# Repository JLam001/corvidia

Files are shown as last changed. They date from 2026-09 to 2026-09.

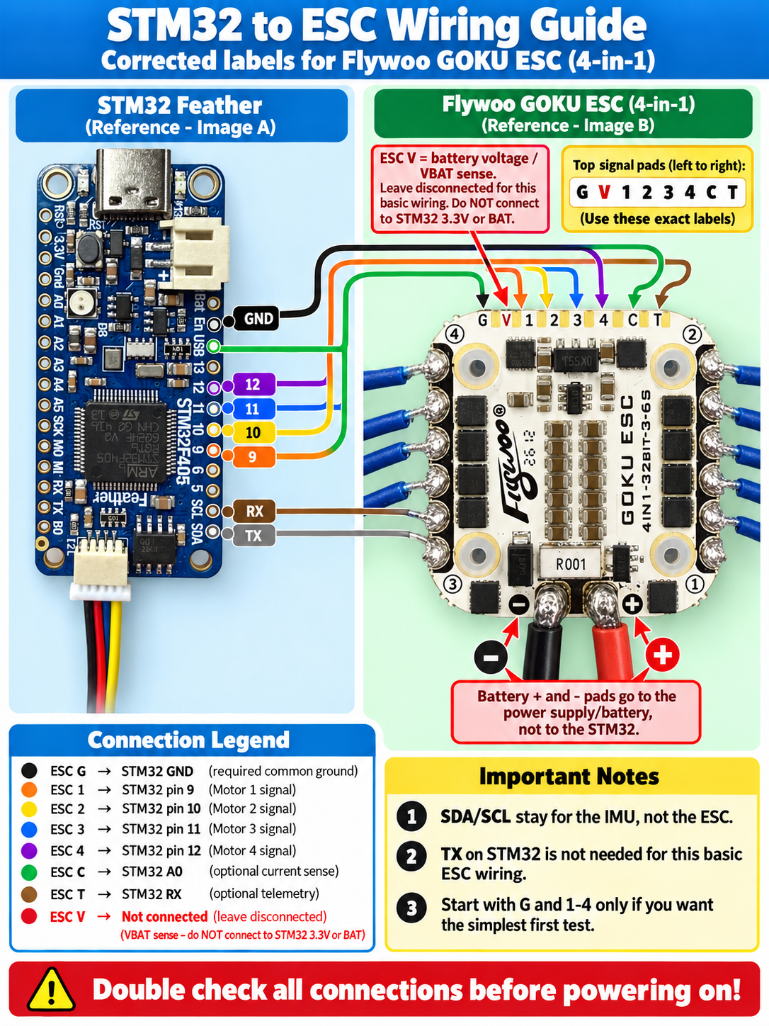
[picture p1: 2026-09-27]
docs/references/control/user-wiring-3.png

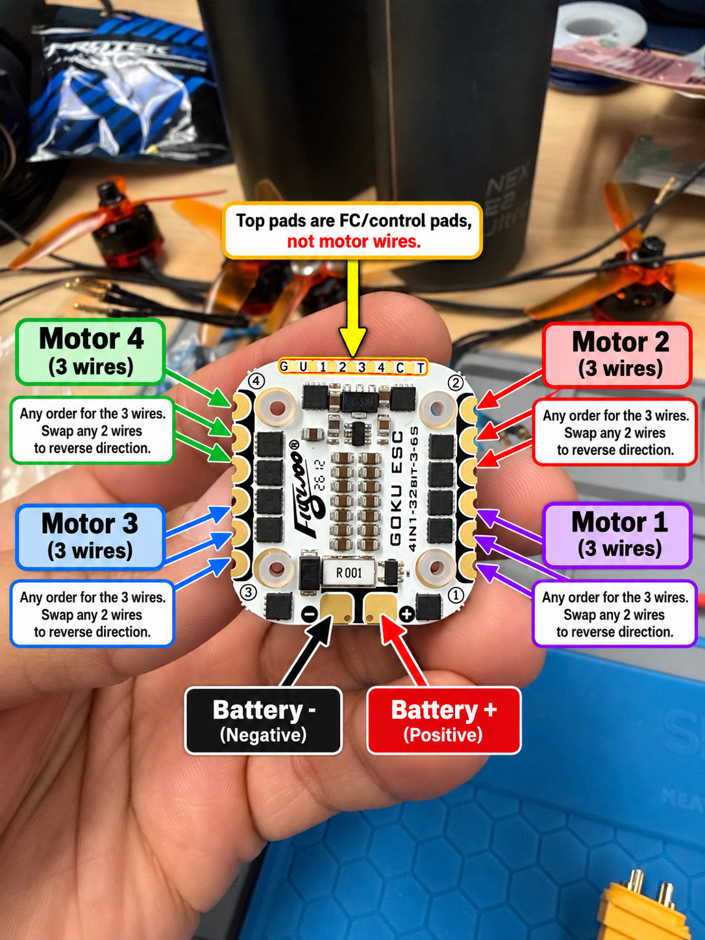
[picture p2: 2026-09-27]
docs/references/control/user-wiring-1.png

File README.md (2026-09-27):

# Corvidia

Project repository for the Corvidia bench demonstrator.

## Mechanical frame

The final frame, editable CAD, manufacturing references and print setup live in
[`hardware/frame/`](hardware/frame/README.md).

- [Prepared P2S PLA print project](hardware/frame/output/Compact_P2S_PLA/Corvidia_Compact_P2S_PLA_Motor_Holes_Fixed.3mf)
- [Print and assembly guide](hardware/frame/output/Compact_P2S_PLA/START_HERE.md)
- [Complete frame package](hardware/frame/output/Corvidia_Compact_One_Print.zip)

The frame has a flat center for a 95 × 111 mm tray, four reinforced motor arms,
and a braced camera mount. It prints on one 256 × 256 mm plate. Physical hardware
fit and operating checks are documented in the guide.

## Software

- [Onboard mission console](perception/STAND_DEMO.md): search briefs, timed
  collection, saved images, and the tested 5% motor-input demo profile.
- [Perception pipeline](perception/README.md): person detection, tracking, and video replay.
- [Event pipeline design](docs/event-pipeline.md): confirmation and evidence workflow.
- [STM32 firmware import](firmware/IMPORT.md): BNO085 IMU polling, MAVLink telemetry,
  command handling, and host-test results.
- [Motor controls and corrected wiring](firmware/MOTOR_CONTROL.md): individual ESC
  tests, the planned motor layout, and bounded movement proposals.
- [Firmware guide](firmware/README.md): PlatformIO setup, installed v5 bench
  firmware, and the prepared v6 startup ramp.

## Repository layout

```text
docs/             # Software architecture and design
perception/       # Jetson person detection/event pipeline
firmware/         # Feather STM32F405 PlatformIO project
hardware/
  frame/
    cad/          # Parametric CAD, build/check scripts and printer profiles
    references/   # Manufacturer geometry and drawings
    output/       # Final print files, CAD exports and verification records
```

Mechanical files live under `hardware/`; Jetson software and STM32 firmware
are separate projects under `perception/` and `firmware/`.

## Get the complete files

Large CAD and print files use Git LFS. Install Git LFS, then run:

```sh
git lfs install
git clone https://github.com/JLam001/corvidia.git
cd corvidia
git lfs pull
```

For an existing checkout, run `git lfs pull` before opening CAD or print files.
See the [frame README](hardware/frame/README.md) for editing and rebuilding.

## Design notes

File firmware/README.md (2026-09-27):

# Corvidia STM32F405 firmware

**Current installed firmware: v5.** It supports selectable operator envelopes through 100% input and
60,000 ms, defaulting to 5% / 500 ms. See [DSHOT_V5.md](DSHOT_V5.md) and the
[installation status](../docs/references/control/dshot-v5-install-2026-09-27.md).
V5 all-four tests at 5% and 7.5% for one second, 50% for 200 ms and two
seconds, and 20% for ten seconds passed user-observed spin/stop checks. This is bench firmware; mission/LLM flight outputs remain unavailable.

**V6 startup ramp is deferred.** Its opt-in source profile is retained in
[DSHOT_V6.md](DSHOT_V6.md), but it has not been installed or verified with
powered motors. The active Jetson adapter requires v5; the prepared v6 host
changes are archived outside this checkout. V5 applies requested input
immediately. The default PlatformIO build remains the IMU-only `feather_f405`
profile, so v5 and v6 motor-capable images both require explicit selection.

PlatformIO + STM32duino firmware for the Adafruit Feather STM32F405 and BNO085.
See [IMPORT.md](IMPORT.md) for provenance and [MOTOR_CONTROL.md](MOTOR_CONTROL.md)
for motor wiring, bench interlocks, and the future movement interface.

**DShot individual and all-four bench pulses passed observed spin/stop checks**
at 1% input for 200 ms, followed by all four at 5% for 500 ms. See the [test record](../docs/references/control/dshot-powered-tests-2026-09-27.md).
Legacy PWM remains blocked after its earlier motor-4 incident. Disconnect the ESC
battery between bench sessions.

## Firmware builds

| Environment | Behavior |
| --- | --- |
| `feather_f405` (default) | IMU + MAVLink over USB; no motor outputs |
| `feather_f405_bench` | Motor-test protocol with hardware outputs disabled |
| `feather_f405_bench_pwm` | Explicit PWM bench image; no IMU or flight stabilization |
| `feather_f405_pwm_diagnostic` | Measures output-pad pulse timing; ESC battery must be disconnected |
| `feather_f405_dshot_diagnostic` | DShot diagnostic with signal pads held low |
| `feather_f405_dshot_signal` | DShot300 zero-throttle frames only; ESC battery must be disconnected |
| `feather_f405_dshot_imu` | IMU + bounded command protocol; ESC signals disabled |
| `feather_f405_dshot_imu_signal` | IMU + zero DShot frames; nonzero commands disabled |
| `feather_f405_dshot_imu_bench` | IMU + explicitly enabled individual or all-four tests; short bench pulses verified |
| `feather_f405_dshot_imu_ramp` | Deferred v6 candidate with a fixed five-second startup ramp; not installed or powered-verified |
| `native` | Hardware-independent C++ tests |
| `native_ramp` | Hardware-independent ramp tests compiled with the v6 identity/capability |

See [DSHOT.md](DSHOT.md) for the new STM32 driver, its MAVLink diagnostics and
validation limits. The combined individual/all-four DShot bench image is now v5, flashed and
verified byte-for-byte; see the installation record for live verification status. It includes the IMU sequence freshness
fix. Live attitude/quaternion telemetry runs at about 50 Hz; both test modes
are reported available, all startup inputs are zero, and stop is acknowledged. Switching test modes needs no reflash.
Both modes require explicit commands and default to a 5% input / 500 ms envelope.
V5 supports explicit envelopes up to 100% / 60 seconds; input is not measured RPM. DShot execution requires per-test readiness; simultaneous
execution also requires individual physical stop checks. Flight control is unavailable.

The [mission control candidate](MISSION_CONTROL.md) adds selectable mission
duration, a configurable ceiling up to 100%, a separate nominal collective,
bounded LLM movement intents and session expiry. It is tested offline and is not
connected to ESC outputs or dispatched by the installed firmware.

The default source sends HEARTBEAT, ATTITUDE, ATTITUDE_TARGET and STATUSTEXT.
ATTITUDE_TARGET is a command echo, not a measured attitude. The default source
now gates ATTITUDE on separate attitude/gyro freshness checks. The shared IMU
wrapper uses game rotation vector (relative yaw), validates reports and clears
health on reset. Message arrival alone does not prove sensor capture latency.

The board observed on September 27 also sent ATTITUDE_QUATERNION, SYS_STATUS,
SERVO_OUTPUT_RAW, SYSTEM_TIME and EXTENDED_SYS_STATE. That running image has not
yet been matched to source. It was backed up and restored byte for byte after
the PWM bench investigation; its 50 Hz attitude stream was verified again.
It has since been backed up again before installing the zero-throttle DShot
diagnostic. Do not assume the original image implements the local bench protocol.

```sh
cd firmware
pio run -e feather_f405
pio test -e native
```

## Live MAVLink IMU dashboard

From the repository root:

```sh
python3 -m venv .venv-control
.venv-control/bin/python -m pip install -r firmware/tools/requirements-control.txt
.venv-control/bin/python firmware/tools/imu_viz.py
```

Open **http://127.0.0.1:8765**. The dashboard provides:

- 3D orientation, roll/pitch/yaw in degrees, gyro rates in degrees/second.
- A 15-second gyro plot, message rate, packet age, heartbeat and board messages.
- Reported gyro/accelerometer health and reported output pulses when available.
- A stale indication after 500 ms without valid ATTITUDE; automatic USB reconnect.
- DShot mode, IMU freshness, command limits enabled/disabled, faults and requested
  motor inputs when the integrated firmware is installed. Motor RPM is unavailable.

It only listens. It sends no MAVLink packets, heartbeats, arming or motor commands.
The HTTP server binds to localhost. No external web assets are needed.
Only one application should own the serial port: close any serial monitor first,
and stop this dashboard with Ctrl+C before running the motor tool.

Auto-detection only selects STM32 USB VID/PID `0483:5740`. It refuses to guess
between multiple boards. Override with `--port /dev/cu.usbmodem...`; source IDs
default to `1/1` and can be set using `--system` and `--component`.

### Interpreting the display

MAVLink ATTITUDE uses radians and rad/s; the dashboard converts both to degrees.
Axes follow the reported sensor frame. Verify physical sensor mounting and the
sensor-to-airframe transform before using this orientation for stabilization.
A roll near ±180° means the reported frame is inverted relative to zero roll;
the visualizer deliberately does not hide that with an automatic zero offset.

SYS_STATUS health flags and SERVO_OUTPUT_RAW values are firmware reports.
They do not independently measure I2C freshness, ESC acceptance, or motor RPM.
An unknown value is shown as unavailable. Disconnection dims the last orientation.

Protocol reference: [MAVLink common messages](https://mavlink.io/en/messages/common.html#ATTITUDE).

## Uploading

See the full [bench instructions](MOTOR_CONTROL.md) before changing images.
The Feather F405 enters ROM DFU with **BOOT0 tied to 3.3 V, then RESET**.
Remove the BOOT0 jumper before resetting into the application. Disconnect ESC
telemetry from RX during DFU; the ROM bootloader also listens on serial interfaces.
Keep motor power disconnected during flashing.

Manufacturer: [Feather F405 DFU details](https://learn.adafruit.com/adafruit-stm32f405-feather-express/dfu-bootloader-details).

## Host checks

```sh
.venv-control/bin/python -m unittest discover -s firmware/tools -p 'test_*.py' -v
```

These cover MAVLink wire decoding, unit conversion, stale/disconnected display
state, source filtering, rejected invalid samples, reconnect state, and motor
command bounds. They do not replace hardware verification.

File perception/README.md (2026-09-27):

# Perception: person detection event pipeline

For the integrated camera, person-description mission, live IMU, and bounded
motor interface, see the [stand demo guide](STAND_DEMO.md). Its default
observation mode uses real perception with simulated motor commands.
Ordinary briefs stop after the first saved match. A brief such as
**find as many people as possible within 30 seconds** collects matching images
for the requested duration (1–60 seconds). The console shows the capture count
and latest image; the full collection is stored on the Jetson. See
[timed collection missions](STAND_DEMO.md#timed-collection-missions) for behavior
and counting limits.

Implements [`docs/event-pipeline.md`](../docs/event-pipeline.md):

- **Step 1, event core:** typed records, candidate lifecycle, bounded queues, stub
  confirmer, evidence writer, deterministic detection-event tests.
- **Step 2, video replay:** YOLO11n + explicitly configured ByteTrack, every-frame
  and real-time replay, live CSI camera source, MJPEG preview, run reports.
- **Step 3, local Cosmos:** Cosmos Reason 2 2B (Q4_K_M) on llama.cpp behind the
  confirmer interface, a labeled starter crop set, and an evaluation tool.
- **Step 4, Jetson CSI:** GStreamer capture with Argus buffer timestamps,
  selectable sensor mode (default 1080p from the binned 1080p60 mode), power
  mode in reports, a 10 s timeseries for drift, and a detached soak runner.
- **Depth and best shot:** per-event metric distance from Depth Anything V2 Metric
  Small (TensorRT, uncalibrated until checked with a tape measure) and the
  clearest full-resolution view of each tracked person (`best.jpg`).
- **Step 5 tooling:** clip recorder and a YOLO-alone vs YOLO + Cosmos scorer.
- The live detector runs the YOLO11n TensorRT engine directly (no PyTorch or
  Ultralytics at runtime) with a NumPy ByteTrack.

## Layout

```text
src/corvidia_perception/
  records.py        # frames, detections, candidates, results, skips
  config.py         # settings from the spec (TOML-loadable), not yet calibrated
  crop.py           # 20% padded crop, size/blur gates, frozen copies
  gate.py           # persistence gate, lifecycle, suppression, retry cooldown
  confirm_queue.py  # bounded FIFO, one entry per track, 2 s expiry
  confirmer.py      # backend protocol, strict answer parsing, stub backends
  worker.py         # evidence commit, one active request, deadline, drain/recover
  evidence.py       # atomic writes, storage limits, interrupted-event recovery
  pipeline.py       # EventPipeline wiring + LatestFrameSlot
  health.py         # counters, gauges, faults
  simulate.py       # threaded run on synthetic detections
  detector.py       # detector factory + tracker wrapper with dropped-frame aging
  trt_detector.py   # YOLO on TensorRT: letterbox, zero-copy managed buffers, NMS
  bytetrack.py      # ByteTrack (NumPy), matches Ultralytics' tracker output
  cosmos.py         # llama-server adapter: JSON-schema answers, cancel + idle check
  cosmos_eval.py    # corvidia-cosmos-eval: accuracy/latency on labeled crops
  trt_runtime.py    # shared TensorRT runner (mapped pinned buffers via ctypes)
  depth.py          # Depth Anything V2 metric distance per event
  depth_check.py    # corvidia-depth-check: live distance readout for calibration
  best_shot.py      # clearest crop per track -> best.jpg / best.json
  record.py         # corvidia-record: camera clips for evaluation
  encounter_eval.py # corvidia-encounter-eval: YOLO vs YOLO + Cosmos on clips
  sources.py        # video replay (every/realtime) and Argus CSI camera
  preview.py        # annotated MJPEG preview + /health JSON
deploy/
  cosmos_server.sh  # pinned llama.cpp container for Cosmos
  export_yolo.sh    # build the YOLO11n TensorRT engine
  soak.sh           # detached sustained-load run (start/status/stop)
  run.py            # corvidia-run CLI and run report
```

The detector thread calls `EventPipeline.on_frame(frame, detections)`. The
confirmation worker runs on its own thread (`start()`), or is stepped with
`tick()` in tests using a fake clock.

## Jetson setup (once)

The venv must see the system OpenCV (GStreamer/Argus build) and TensorRT, so it
is created with system site-packages. `pyproject.toml` blocks the pip OpenCV
wheels and pins NumPy < 2 to match the system OpenCV.

```sh
cd ~/corvidia/perception
uv venv --python /usr/bin/python3 --system-site-packages
uv sync --extra detector
mkdir -p ~/models && curl -sL -o ~/models/yolo11n.pt \
  https://github.com/ultralytics/assets/releases/download/v8.3.0/yolo11n.pt
```

The live pipeline uses the FP16 TensorRT engine (`~/models/yolo11n.engine`) and
never imports PyTorch. The `detector` extra (Ultralytics + PyTorch) is only for
exporting the engine, `.pt` comparisons, and parity tests. Build the engine once
(about 10 minutes):

```sh
deploy/export_yolo.sh
```

PyTorch in the tooling extra comes from the `cu130` index, which has no native
sm_87 (Orin) build; `test_gpu_detections_match_cpu` checks its GPU results.

## Cosmos confirmer

```sh
deploy/cosmos_server.sh start    # fetch pinned weights (sha256-checked), run container
deploy/cosmos_server.sh status
```

llama-server runs in the Jetson AI Lab container (pinned by digest) on
`127.0.0.1:8010`, restarting with the system. It uses the community GGUF
`Kbenkhaled/Cosmos-Reason2-2B-GGUF` (Q4_K_M + F16 vision projector) pinned to a
revision, with `-c 2048 -np 1 -cram 0` to keep RAM headroom.

## Run on the Jetson

From the repository root on the Mac:

```sh
rsync -az --delete --exclude='.git' --exclude='.DS_Store' --exclude='.venv' \
  --exclude='__pycache__' --exclude='.pytest_cache' ./ jlam@192.168.2.2:corvidia/
ssh jlam@192.168.2.2 'cd ~/corvidia/perception && ~/.local/bin/uv run pytest -q'
```

On the Jetson (`cd ~/corvidia/perception`):

```sh
# Accuracy replay: every frame, event timing on video time, instant stub answers
uv run corvidia-run --video /usr/share/opencv4/samples/data/vtest.avi --mode every

# Timing replay: real-time pacing (here 4x) with frame dropping
uv run corvidia-run --video /usr/share/opencv4/samples/data/vtest.avi --mode realtime --speed 4

# Live CSI camera with Cosmos, depth and preview at http://192.168.2.2:8080/  (Ctrl-C to stop)
uv run corvidia-run --camera --confirmer cosmos --preview-port 8080

# Confirmer accuracy/latency on the labeled crop set, and failure-path checks
uv run corvidia-cosmos-eval --dataset ~/corvidia-data/eval/starter --checks
```

Useful flags: `--model ~/models/yolo11n.pt` (PyTorch path), `--confirmer cosmos|yes|no|uncertain`,
`--stub-delay 0.8`, `--duration 60`, `--config settings.toml`.
Events default to `~/corvidia-data/events/<session>/`, outside the rsync target,
and each session gets a `run_report.json` (detector/loop/frame-age percentiles,
drops, events, skips, peak RSS, peak system memory, max temperatures).

## Step 3 measurements (Orin Nano 8 GB, 2026-09-27)

Starter crop set (`~/corvidia-data/eval/starter`, 255 crops hand-labeled from
vtest.avi, a live session, background regions, and Megamind.avi animation):

| Model, prompt | Person recall | Confirm precision | Background rejected | Cartoons rejected | Latency p50 / p99 |
|---|---|---|---|---|---|
| Q8_0, default prompt | 121/121 | 0.87 | 30/34 | 1/15 | 1.53 / 2.75 s |
| **Q4_K_M, default prompt (deployed)** | 120/121 | 0.95 | 34/34 | 9/15 | 1.35 / 2.46 s |
| Q4_K_M, "physically present" prompt | 41/121 | 1.00 | 34/34 | 15/15 | 1.26 / 2.40 s |

The model never answered "uncertain". Rewording the prompt swings results
sharply, so prompt changes need a larger held-out set with real screens, photos
and mannequins before they are adopted.

Full stack, 4 min real-time replay with Cosmos Q4 (TensorRT detector, no PyTorch):
0 dropped frames at 10 fps; detector p50 22.5 ms idle vs 36.5 ms while Cosmos
runs (GPU contention); confirmation p50 1.51 s, p99 1.77 s, no timeouts; minimum
available RAM 1.73 GB (desktop session running); max 53.8 °C.

Failure paths against the real server: mid-generation cancel acknowledged with
the server idle after ~1.0 s; a 4K image maps to `context_overflow`; a stopped
server maps to `server_unavailable`.

Memory (camera run, 20 s): TensorRT-only pipeline costs 655 MB and runs the
detector at 22.9 ms p50; the Ultralytics/PyTorch path cost 1,051 MB at 52.7 ms.

## Step 4: camera and sustained load (2026-09-27)

Capture is a GStreamer pipeline read through PyGObject (the venv sees the
system `gi`). Each frame's `capture_ts` is the Argus buffer timestamp on
CLOCK_MONOTONIC (`capture_quality: "argus_buffer_pts"`): the time Argus
delivered the frame, about 4.5 ms before Python receives it. It is not the
exposure time; Argus does not expose sensor timestamps through GStreamer, and
that would need a small C++ Argus capture.

Capture cost by mode (capture only, 15 W):

| Sensor mode -> output | CPU (1 core) | Argus-to-Python | Frame |
|---|---|---|---|
| 1080p60 mode -> 720p @ 30 | 33% | 6 ms | 2.8 MB |
| **1080p60 mode -> 1080p @ 30 (default)** | 44% | 10 ms | 6.2 MB |
| 4K30 mode -> 1080p @ 30 | 43% | 13 ms | 6.2 MB |
| 4K30 mode -> 4K @ 30 | 118% | 38 ms | 24.9 MB |

YOLO letterboxes every frame to 640 px, so resolution mainly sharpens the crops
Cosmos sees. The binned 1080p mode reads out faster (less rolling-shutter skew)
and is less noisy in low light than the 4K mode.

```sh
deploy/soak.sh start 30   # camera + YOLO + Cosmos, detached, preview on :8080
deploy/soak.sh status     # latest timeseries row
deploy/soak.sh stop       # graceful stop; writes run_report.json
```

## Free-space stream (depth thread)

The pipeline order for a moving platform: the depth engine runs on its own thread at a fixed
rate and publishes an obstacle free-space profile, the detector thread tracks people and the
gate stores evidence with per-event distance, and no confirmer sits in the loop. The default
confirmer is the `yes` stub; live runs delay it by `--stub-delay` (0.8 s, to emulate Cosmos
latency), so pass `--stub-delay 0` for the no-confirmer order. Cosmos stays available with
`--confirmer cosmos`.

```sh
uv run corvidia-run --camera --freespace-hz 10 --stub-delay 0 --preview-port 8080
uv run corvidia-run --camera --freespace-hz 10 --stub-delay 0 --freespace-udp 127.0.0.1:5601   # also as JSON datagrams
```

`FreeSpaceStream` (`depth_stream.py`) always works on the newest frame (a one-frame fan-out
from the run loop), turns each metric depth map into seven sector "nearest" distances and free
scores (`freespace.py`, ported from the autodrone framework with the same field names: `t`,
`columns`, `center_free`, `all_close`, `hfov_deg`, `nearest_m`), smooths the nearest distances
with an EMA, and stamps each profile at publish time. Per session it appends
`freespace.jsonl` (one row per publish with the map's `age_at_publish_ms` and `depth_ms`),
sets `freespace_*` health gauges (also in `timeseries.jsonl` and `/health`), and adds a
`freespace` block to `run_report.json`. Parameters live in `[freespace]` of the config
(`n_cols`, `near_percentile`, `band`, `hfov_deg`, `d_stop`, `d_free`, `smooth_alpha`, `udp`).

Budget on the Orin Nano (measured per-call costs, 15 W): depth ~46 ms idle and YOLO ~22.5 ms,
so depth at 10 Hz plus YOLO at 10-15 fps fits with headroom; while a Cosmos confirmation runs,
depth takes 100-140 ms and YOLO 36.5 ms, and a consumer with a 150 ms freshness rule (the
autodrone L3/L4 layers) would see stale free space. The engine is shared with the per-event
distance through a lock in `DepthEstimator.depth_map`; the two take turns. Not yet done:
calibration (`depth.scale`), the outdoor 80 m engine, an attitude-driven band (the fixed
0.35-0.8 band is used until pitch is available), and a rate measurement on the Jetson itself.
Per-frame person tracks can leave the process the same way: `--tracks-udp host:port` sends
`{"t", "frame_id", "source_epoch", "width", "height", "tracks": [{"id", "x1", "y1", "x2", "y2",
"conf", "age", "depth_m"}]}` after every processed frame (`tracks_stream.py`; boxes normalized,
`age` = processed frames seen, `depth_m` = torso median from the newest free-space map or -1).
[`bridge/`](bridge/README.md) turns both streams and the evidence store into the autodrone
mission loop's topics. The laptop evaluation harness and its datasets are in
[`laptop-eval/`](laptop-eval/README.md).

## Depth and best shot

```sh
# once: export and build the engines (conversion venv has torch + transformers)
python tools/export_depth.py ~/models/depth/da2-metric-indoor-small-hf \
    ~/models/depth/da2-metric-indoor-small-294x518.onnx
/usr/src/tensorrt/bin/trtexec --onnx=...onnx --saveEngine=...engine --fp16
# calibrate: stand at taped distances and compare
uv run corvidia-depth-check
```

Depth runs once per event, on the event's frame, on the confirmation worker
thread while Cosmos runs (about 46 ms idle, 100-140 ms under load; 24 ms of GPU
time). Distance is the median over the central torso region of the box. Values
stay `"uncalibrated"` until `[depth] scale` and `calibrated = true` are set.

TensorRT buffers are pinned host memory mapped into the GPU (zero-copy). CUDA
managed memory cannot be used: the Orin reports `concurrentManagedAccess = 0`, so
CPU access during any kernel faults, and YOLO and depth run on different threads.

## Soak and step 5 results (2026-09-27)

30 min soak at 15 W, 1080p, Cosmos Q4: 106 events (98 confirmed, 7 rejected, 1
timeout), confirmation p50 2.06 s / p99 3.00 s, max 54.6 °C. Available RAM fell
from 1.3 GB to 0.92 GB while the camera ran and recovered after it stopped; the
growth is outside the pipeline process and not yet diagnosed.

Step 5 on three recorded clips (people walking, a group, an empty ceiling view):
YOLO alone had 0 false events, so Cosmos removed none; both found 4/4 people.
Track fragmentation produced 32 events for 4 people. Hard negatives (screens,
posters) were not captured, so Cosmos's benefit is still unmeasured.

## Not yet covered

- Merging duplicate events from fragmented tracks (about 8 events per person on
  close-range clips).
- Depth calibration against a tape measure; distances are uncalibrated.
- Argus sensor timestamps: live frames carry host arrival time only.
- Dataset-collection retention quotas and automatic retention policies.
- Hard negatives (screens, printed photos, mannequins, statues) in the eval set,
  and a held-out split for prompt changes.
- Calibrated `person_score` (the spec keeps it null for now).
- YOLO11n and Ultralytics are AGPL-3.0; a commercial product needs a licence or
  a differently licensed detector.

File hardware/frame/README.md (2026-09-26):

# Corvidia — final compact frame

## Print file

[Corvidia_Compact_P2S_PLA_Motor_Holes_Fixed.3mf](output/Compact_P2S_PLA/Corvidia_Compact_P2S_PLA_Motor_Holes_Fixed.3mf)

Open as a project in Bambu Studio. Configured for **Bambu P2S, 0.4 mm standard nozzle, Generic PLA and Textured PEI**. Keep the saved placement at 100% scale; do not auto-arrange.

- One connected part on one 256 × 256 mm plate.
- Approximately 6h 4m and 185 g PLA, including supports and brim.
- Flat 110 × 116 mm center for the user's 95 × 111 mm tray.
- Arms taper from 28 mm roots to 20 mm ends; 6 mm deck and motor pads.
- Four motor mounts and a braced, forward-facing camera bracket.
- Verified open motor screw and center relief holes in the sliced paths.

See the [print and assembly guide](output/Compact_P2S_PLA/START_HERE.md) for hardware, placement and physical checks.

## Files kept

| Location | Contents |
|---|---|
| `output/Compact_P2S_PLA/` | Final print project, FreeCAD, STEP, STL, guide, previews and current verification records |
| `output/Corvidia_Compact_One_Print.zip` | Final package, including CAD sources, profiles and component references |
| `cad/` | Final build, slicing and verification scripts; shared geometry definitions and parameters |
| `cad/profiles/` | P2S machine, Generic PLA and final process settings |
| `references/` | Component source geometry/drawings needed to understand and rebuild the design |

## Edit and rebuild

Run `cad/Open_Compact.FCMacro` in FreeCAD to open the editable model with its Python definitions loaded. The model uses named spreadsheet parameters and procedural solids.

From this workspace on this Mac:

```sh
PYTHONPATH=/Applications/FreeCAD.app/Contents/Resources/lib /Applications/FreeCAD.app/Contents/Resources/bin/python cad/compact_frame.py
python3 cad/slice_compact.py
python3 cad/check_compact.py
```

The slicer script defaults to `/Applications/BambuStudio.app`; use `--app` to specify another installation. Python verification requires Pillow. `cad/prepare_references.py` regenerates the Orin cache from the retained manufacturer STEP if needed.

Rebuilding replaces generated outputs and creates temporary files under `tmp/`. The saved print project and CAD have passed software checks; physical tray fit, adhesive, motor screw engagement, assembled balance, temperatures, strength and bench restraint still require hardware checks.

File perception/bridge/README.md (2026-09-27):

# Corvidia -> autodrone bridge

`corvidia_bridge.py` is the process that lets the autodrone mission loop run on top of this
pipeline. `corvidia-run` owns the camera and the GPU models and publishes two UDP streams; the
bridge turns them, plus the evidence store, into the bus topics the framework's nodes consume.

| Bus topic | Source in Corvidia | Notes |
|---|---|---|
| `perc.freespace` | `corvidia-run --freespace-hz 10 --freespace-udp 127.0.0.1:5601` | FreeSpace fields forwarded unchanged, stamped at Corvidia's publish time |
| `perc.tracks` | `corvidia-run --tracks-udp 127.0.0.1:5602` | PersonTracks fields unchanged: normalized boxes, id, conf, age (processed frames seen), depth_m (torso median from the newest depth map) |
| `health.perception` | liveness of the tracks stream | stale after `stale_s` (1 s); free-space staleness only appears in the detail, because the mission guard judges free-space age itself |
| `health.camera` | frame ids advancing in the tracks stream; Corvidia `/health` faults `camera`, `source`, `memory_low` when `health_url` is set | |
| `capture.event` | each completed `event.json` in the newest session under `events_root` | paths: frame.jpg, crop.jpg, best.jpg (waits up to `best_grace_s` for the best shot); `verified` = yes / no / unknown from Cosmos, `unverified` with a stub; events completed before the bridge started are not replayed |
| `cam.frame` (optional) | Corvidia's MJPEG preview (`--preview-port 8080`, `preview_url = "http://127.0.0.1:8080/stream"`) | JPEG frames at `frame_hz`; they carry the drawn boxes, so they serve the CAPTURE burst and the context frame, not clean evidence |

## Running it on the Jetson

```sh
# Corvidia side (its own venv)
cd ~/corvidia/perception
uv run corvidia-run --camera --freespace-hz 10 --stub-delay 0 \
    --freespace-udp 127.0.0.1:5601 --tracks-udp 127.0.0.1:5602 --preview-port 8080

# autodrone side (its environment: pyzmq + the autodrone package)
cd ~/autodrone
python -m autodrone.launch --profile configs/host-jetson.toml --only broker,fc,control,mission
python ~/corvidia/perception/bridge/corvidia_bridge.py --profile configs/host-jetson.toml
```

Do not start the framework's `camera` or `perception` nodes: both would open the same Argus
sensor and run a second detector. The profile may carry a `[corvidia_bridge]` section (every key
optional; defaults shown in the module docstring): ports, `stale_s`, `events_root`, `session`,
`publish_capture`, `best_grace_s`, `health_url`, `preview_url` (the `/stream` endpoint), `frame_hz`. Set `depth_kind = "metric"` in the
profile's perception section if anything on the framework side still assumes the relative model;
the free-space thresholds (`d_stop` 3 m, `d_free` 6 m) are applied on the Corvidia side.

What the mission then sees, in pilot-assisted mode (autodrone `states.py` / `guards.py`):
entering SCOUT needs healthy FC, PERCEPTION and CAMERA; SCOUT and CENTER hold while PERCEPTION
stays healthy and `perc.freespace` stays fresh (older than `depth_stale_s` for `depth_stale_grace_s`
means STOP); `all_close` is not a state change but a controller backoff; a track with `age >= 3`
moves SCOUT to CENTER; CAPTURE needs CAMERA and reads `cam.frame` for its burst (or logs "no camera
frames" and falls to COOLDOWN after 3 s if `preview_url` is unset) while `capture.event` carries
Corvidia's own evidence. With `send_commands = false` nothing reaches the board.

## Tests

`test_bridge.py` covers everything that does not need the bus: UDP receive, datagram
conversion, liveness and heartbeat rules, event tailing across sessions, JPEG dimension parsing
and MJPEG splitting. It runs with the package suite (`uv run pytest -q`; `bridge` is in
`testpaths`). The node itself imports autodrone only when started.

The laptop harness can drive the whole chain without the Jetson:
`laptop-eval/tools/mimic_pipeline.py ... --freespace-udp 127.0.0.1:5601 --tracks-udp 127.0.0.1:5602`,
then the framework's broker and this bridge from the autodrone environment.

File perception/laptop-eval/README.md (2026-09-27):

# Laptop evaluation harness

Runs the perception pipeline on a laptop against public datasets, without the Jetson, and
documents the datasets and results behind the `perception-pipeline` branch. On the Jetson the
same pipeline order is one command (see the main README, "Free-space stream"):

```sh
uv run corvidia-run --camera --freespace-hz 10 --stub-delay 0   # depth thread + YOLO + gate + evidence, no Cosmos
```

What is real here and what is substituted:

| Stage | Jetson | Laptop |
|---|---|---|
| Source | Argus CSI camera or recorded clip | ingested clip directory (same format as `corvidia-record`) |
| Free-space stream | `FreeSpaceStream` + Depth Anything V2 Metric Small on TensorRT | same `FreeSpaceStream`, same model via transformers on CPU |
| Detector | YOLO11n FP16 TensorRT engine | same YOLO11n weights, Ultralytics on CPU |
| Tracker, gate, queue, worker, evidence, best shot | unchanged | unchanged |
| Confirmer | Cosmos (optional) | stub `--confirmer yes` (also the Jetson default) |

## Setup

```sh
cd perception/laptop-eval
./setup.sh              # .venv with CPU torch, ultralytics, opencv, transformers; yolo11n.pt; depth checkpoint
./fetch_datasets.sh     # DanceTrack (3 smallest clips) and MOT17-05, ingested into clips/
```

## Datasets

Used for the results below (fetched by `fetch_datasets.sh`):

| Dataset | Hugging Face id | What it tests | License | Size fetched |
|---|---|---|---|---|
| DanceTrack | `Voxel51/DanceTrack` | 25 fps 1080p mp4, per-frame boxes with identities, head-height, indoor and outdoor groups | CC BY 4.0 | 3 clips, ~23 MB + 83 MB annotations |
| MOT17-05 | `Lekim89/MOT17` (mirror of MOTChallenge) | 14 fps 640x480, moving street-level camera, 88 annotated people, ignore regions and distractor classes | upstream CC BY-NC-SA 3.0 (research use only) | one sequence, ~30 MB |

Other options verified in the 2026-09-27 dataset sweep (not fetched by default):

| Dataset | Hugging Face id | Fit | License |
|---|---|---|---|
| VisDrone2019-MOT | `huseyincavus/visdrone2019-mot` | real UAV footage, oblique from tens of metres, people small; 1.64 GB val split | CC BY-NC 4.0 |
| P-DESTRE | `2uanDM/p-destre` | DJI at 5.5-6.7 m, 45-90 degree pitch, closest to a quadcopter view; 30 fps 4K mp4 with identities; selective download from a 72 GB tar | uploader tag Apache-2.0, upstream research use |
| UAV123 (person sequences) | `xche32/UAV123` | drone following one person at 5-25 m, 30 fps; single 14 GB tarball | not stated |
| Print attack sample | `AxonData/print-attack-dataset` | 15 clips of a camera on a printed photo of a person: hard negative for the confirmer, runs through the whole pipeline | CC BY 4.0 |
| Replay attack sample | `AxonData/Replay_attack_mobile` | 39 clips of a phone filming a screen showing a person: hard negative | CC BY 4.0 |
| PA-100K | `tuandunghcmut/PA-100K` | 100k real surveillance person crops for confirmer positives | CC BY 4.0 |
| COCO 2017 person val | `naufalso/coco-2017-person-val` | still images, detector-only precision/recall | COCO terms |

Any MOTChallenge-style sequence (`img1/`, `seqinfo.ini`, `gt/gt.txt`), FiftyOne video export, or
plain video with a MOT `gt.txt` ingests with `tools/ingest.py`. Clip names must not contain a dot.

## Ingest, run, score

```sh
V=.venv/bin/python
$V tools/ingest.py mot data/mot17/train/MOT17-05-FRCNN --out clips/mot17-05
$V tools/ingest.py fiftyone data/dancetrack/data/dancetrack0008.mp4 \
    --frames data/dancetrack/frames.json --samples data/dancetrack/samples.json --out clips/dancetrack0008
$V tools/ingest.py video some_clip.mp4 --out clips/print-attack-01       # spoof clip, no gt

./run_clip.sh dancetrack0008              # YOLO-alone arm: accuracy replay -> autolabel -> score
./run_clip.sh print-attack-01 --depiction # every track is a depiction, no people
```

Clips are `000000.jpg...` plus `frames.jsonl` with `capture_ts = index / fps` from the dataset's
true frame rate (so the gate's 1 s window is right at 14 fps), `gt.txt` in MOT format, and
`clip.json` with provenance. Frames are re-encoded once at quality 95 at native resolution;
`--max-side` exists only to emulate a camera output size (YOLO letterboxes to 640, depth resizes
to 518x294, and confirmer crops are capped at 448 px regardless).

`tools/autolabel.py` turns `gt.txt` into the `corvidia-encounter-eval` label file: each track's
first event box is matched at its frame by IoU (0.5 person, 0.2 partial, overlap with a MOT
distractor or reflection row = depiction, else not_person). Tracks it will not guess at are left
unlabeled and listed by the scorer: overlaps with ignore regions (conf 0), unmatched boxes at the
frame edge (on MOT17-05 every one was a real person entering or leaving that the annotators did
not box), and frames with no gt. Review those with `corvidia-encounter-eval sheets` and label by
hand; hand labels are never overwritten. A clip's "people" are gt identities with 15+ frames at
visibility >= 0.5, height >= 48 px and width >= 24 px (the crop gate's minimums).

## The pipeline order with the free-space stream

```sh
$V tools/mimic_pipeline.py clips/mot17-05 --events runs/mot17-05 --mode realtime --depth-hz 10
# emulate compute 4x faster than the laptop: replay 4x slower and scale every time constant 4x
$V tools/mimic_pipeline.py clips/mot17-05 --events runs/mot17-05 --mode realtime \
    --speed 0.25 --depth-hz 2.5 --stale-s 0.6 --control-hz 5 --grace-s 2.0
```

Add `--freespace-udp 127.0.0.1:5601 --tracks-udp 127.0.0.1:5602` to feed the bridge in
[`../bridge/`](../bridge/README.md) from the laptop (verified 2026-09-27 with the framework's
broker: 110 track messages, 27 free-space profiles, 11 capture events and healthy heartbeats
reached the bus during a DanceTrack replay).

This drives the packaged `FreeSpaceStream` with the CPU depth model and replays a virtual 20 Hz
controller against `freespace.jsonl`: the fraction of ticks that saw free space younger than the
consumer's rule (150 ms, from the autodrone framework's L3/L4 guards) under both stamping choices,
and how often the L4 guard (stale for 0.5 s) would have fired.

## Results, 2026-09-27

YOLO-alone arm, accuracy replay (every frame, laptop CPU):

| Clip | People | Tracks | False | Precision | Found | Duplicate events | Unlabeled |
|---|---|---|---|---|---|---|---|
| DanceTrack 0008 | 8 | 26 | 0 | 1.00 | 8/8 | 18 | 0 |
| MOT17-05 | 52 | 132 | 3 | 0.975 | 46/52 | 30 | 11 |

Free-space stream + detector, real time (laptop CPU; both PyTorch models contend for the same
cores) and 4x dilated (video-time equivalents, gate/queue windows scaled):

| Run | YOLO fps | Depth Hz (target 10) | Depth inference | Fresh ticks, stamp at publish / capture | Guard stops | Events | Found | Precision |
|---|---|---|---|---|---|---|---|---|
| DanceTrack, real time 1x | 5.5 | 1.2 | 596 ms | 18 % / 0 % | 14 / 1 | 6 | 5/8 | 1.00 |
| MOT17-05, real time 1x | 4.5 | 1.9 | 480 ms | 28 % / 0 % | 3 / 1 | 2 | 2/52 | 1.00 |
| DanceTrack, 4x dilated | 17.0 | 4.6 | 157 ms | 68 % / 0 % | 0 / 1 | 20 | 8/8 | 1.00 |
| MOT17-05, 4x dilated | 14.0 (0 dropped) | 5.0 | 139 ms | 72 % / 0 % | 0 / 2 | 129 | 46/52 | 0.983 |

Reading: at 1x the laptop cannot run both models at rate, the detector starves the gate and the
guard would stop the mission repeatedly. With 4x more compute the detector keeps up, events and
recall return to accuracy-mode levels, and the structure meets the guard only when free space is
stamped at publish time; stamping at capture counts the map's own age (~210-240 ms here, ~56 ms
with the Jetson engine) and fails every tick. Depth reaches half its target because this CPU's
inference is 140-160 ms video-time against the engine's 46 ms. Duplicate events are cross-track
fragmentation (one person, several track ids), the dominant open issue. Depth is uncalibrated
(`scale` 1.0); MOT17-05 is 4:3, so its depth input was stretched by a third.

The JSON reports behind both tables are in `results/2026-09-27/`.

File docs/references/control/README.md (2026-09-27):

# User-provided control references

Copied from Downloads on September 27, 2026:

- `HANDOFF-2026-09-27.md`: original `HANDOFF.md`, describing the perception project.
  It describes commits and uncommitted Jetson work beyond this checkout. This is
  a reference snapshot, not proof that those files or measurements exist locally.
- `user-wiring-1.png`: `ChatGPT Image Sep 27, 2026, 01_17_20 AM.png`.
- `user-wiring-2.png`: `ChatGPT Image Sep 27, 2026, 01_17_36 AM.png`.
- `user-wiring-3.png`: `ChatGPT Image Sep 27, 2026, 01_17_44 AM.png`.

The images are annotated/generated references, not an electrical inspection.
Their arrows and pin labels conflict in places. In particular, Feather D11/D12
do not support hardware PWM. Use the verified manufacturer pin assignments and
the correction table in [MOTOR_CONTROL.md](../../../firmware/MOTOR_CONTROL.md).

User clarifications:

- ESC identified as Flywoo GOKU G45M AM32; see [ESC-G45M-AM32.md](ESC-G45M-AM32.md).

- Propellers removed; user subsequently confirmed all four motors mounted or clamped.
- Initial wiring: ESC V disconnected; optional C and T connected. T was
  subsequently disconnected for the DShot tests and remains disconnected in
  the current stand demo.
- ESC channels 1/3 are planned at the rear; 1/2 on the right, facing forward
  from behind the camera. Thus FL=4, FR=2, RL=3, RR=1.
- User confirmed moving ESC 3 from Feather 11 to 6, and ESC 4 from 12 to 5.
  Electrical continuity has not been independently measured.

The user separately requested a low-speed motor test in the conversation.
The live MAVLink check is recorded in `bench-check-2026-09-27.json`; that
read-only check does not verify physical ESC response or measured motor RPM.

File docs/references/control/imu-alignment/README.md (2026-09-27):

# IMU axis check — 2026-09-27

The operator confirmed ESC battery disconnected, props removed, USB connected
and BNO085 rigidly mounted. The frame could not be made level, so its current
resting pose was used only as a relative reference. No zero/level calibration,
firmware upload, heartbeat or motor command was sent.

The operator confirmed each requested pose before capture. All captures contain
about 50 Hz attitude and quaternion telemetry, IMU_OK=1, IMU_REJ=0,
DS_FAULT=0, DS_ACTIVE=0 and zero requested motor input. DS_TOKEN remained 7.

| Physical motion | Relative sensor rotation vector (degrees) | Dominant axis |
| --- | --- | --- |
| Right side lowered | −23.51, +4.03, −3.03 | −X |
| Front/camera raised | −1.89, +26.83, +2.77 | +Y |
| Camera turned right | −3.09, −3.09, −32.26 | −Z |

Comparisons use conjugate(reference quaternion) × pose quaternion, normalized
and sign-aligned, with the final half of each eight-second capture averaged.
The relative-reference calculation is tested with nonlevel synthetic poses.
The first nose-up and yaw samples failed the three-degree stationary-spread
criterion; both were retained as rejected evidence and repeated. Accepted pose
spreads were approximately 0.70°, 1.50°, and 1.41° respectively.

The candidate sensor-to-body vector map is diag(−1,+1,−1), a proper rotation.
This identifies dominant axes/signs. Hand-positioned cross-axis motion is too
large to claim a precise mounting matrix. An absolute attitude transformation
and a deliberate motion/rate consistency check are still required. Do not simply
negate isolated Euler readings and declare flight calibration complete. The
current firmware still publishes its original sensor-frame attitude and gyro.

## Controller correction signs (software only)

Using the user-confirmed rotor pattern (1/4 CW, 2/3 CCW) and synthetic test gains:

- Right side down: increase right motors 1/2; decrease left motors 3/4.
- Nose up: increase rear motors 1/3; decrease front motors 2/4.
- Turning right: increase CW rotors 1/4; decrease CCW rotors 2/3.

All six mixer/controller unit tests pass, including the new restoring-direction
test for this layout. The three relative-quaternion analysis tests pass. This
checks software signs only; real stabilization gains and powered closed-loop
behavior remain unverified. Flight output stays gated.

See [assessment.json](assessment.json) for computed results and individual JSON
files for full timestamped MAVLink messages.

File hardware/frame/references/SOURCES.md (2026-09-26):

# Component reference register

Retrieved 2026-09-26. Dimensions are millimetres. `cad/parameters.json` and the
FreeCAD `Parameters` spreadsheet identify the provenance of each dimension.

| Item | Source and local evidence | Interpretation |
|---|---|---|
| Orin Nano | [NVIDIA manufacturer STEP](https://developer.nvidia.com/downloads/assets/embedded/secure/jetson/orin_nano/docs/jetson_orin_nano_devkit_3d_step_model.zip); `P3766-P3768SKU4-P3767ENVELOPE.stp` | Carrier 100 x 79; cooler top 29.866 above carrier bottom. Native board bounds X=-4..96, Y=-17..62, Z=0..1.57. Selected holes native (0,0), (86,0), (0,58), (86,58), radius 1.375. Other mounting holes also exist. |
| Feather #4382 | [Adafruit Eagle PCB](https://github.com/adafruit/Adafruit-Feather-STM32F405-Express-PCB), `feather.brd` | Mount coordinates X=2.54/48.26, Y=2.54/20.32; 45.72 x 17.78 pitch. Two plain holes and two packaged holes. M2 mounting clearance is a design choice. Assembly envelope 52 x 23 x 10 is retained from the supplied plan. |
| BNO085 #4754 | [Adafruit Eagle PCB](https://github.com/adafruit/Adafruit-BNO08x-PCB), `bno08x.brd` | Mount coordinates X=2.54/22.86, Y=2.54/20.32; 20.32 x 17.78 pitch. Legacy master board reference; confirm physical revision. |
| G45M ESC | [Flywoo specification via GetFPV](https://www.getfpv.com/flywoo-goku-g45m-45a-3-6s-am32-4-in-1-esc-20x20.html) | Plan dimensions 33 x 30 x 6.1 and 20 x 20 M2 grommet mounting. Component is represented as an assembly envelope, not manufacturer CAD. |
| RS2205 | [Readytosky](https://readytosky.com/e_productshow/?271-RS2205-2300kv-CWCCW-Brushless-Motor-271.html=) | Diameter 27.9, published overall length 31.7. Body-only height 24 is a provisional design envelope. The 11.5 square pitch is the user's measurement and takes precedence over generic motor patterns. |
| HQProp 4x4.3x3 V1S | [HQProp](https://www.hqprop.com/hq-durable-prop-4x43x3v1s-2cw2ccw-poly-carbonate-p0184.html) | 101.6 swept diameter, 13 x 5.7 hub, 5 bore. Published hub height does not establish blade Z sweep. |
| B0249 | [Arducam drawing via UCTRONICS](https://www.uctronics.com/download/Amazon/B0249_IMX477_HQ_Camera_for_Jetson_Datasheet.pdf), `B0249_datasheet.pdf`, printed pages 2 and 4 | 38 square PCB, 34 outer mounting pitch, lens diameter 30 x length 31, horizontal FOV 65 degrees. Drawing does not establish complete assembled depth. 45 mm depth from PCB front is provisional. |

## Orin alignment

The Orin manufacturer CAD used by this design is retained in full in this folder.
The preview omits the stock base and its four carrier screws (solid indices
1266..1270), the Wi-Fi module and its screw (1377..1378), and antennas/coax
(1380..1392). These are identified from STEP product order, part labels and bounds:
`330-0266-000_M2_WIFI_MODULE_ASM`, `WIFI_ANTENNA_P3526`, and coax/antenna assemblies.
The NVMe assembly (1271..1376, plus mounting screw 1379) is retained as a conservative
optional storage reference. The fan/heatsink and carrier remain intact. Native
solid bounds and volumes are recorded in `orin_solids.json`. Remove the matching
physical wireless hardware for the wired demonstration.

Transform native points by subtracting (46,22.5,0), rotating -90 degrees around Z,
and translating Z to 14 for the current nominal user-tray placement. This puts rear I/O toward frame -X. The selected mounting
pattern becomes X=-22.5/35.5, Y=-40/46: its centre is (6.5,3), not the board centre.
The build uses the actual manufacturer shape and derives Z from the deck height plus the assumed tray lift. The user tray height remains unmeasured.

`orin_without_base.brep` is a reproducible local cache made by
`cad/prepare_references.py`; it is not a substitute source. Native shape order is
validated before extracting the base. See `sha256.json` for source fingerprints.

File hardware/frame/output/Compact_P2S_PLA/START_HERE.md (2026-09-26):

# Corvidia Compact — flat center for your own tray

Open **`Corvidia_Compact_P2S_PLA_Motor_Holes_Fixed.3mf` as a project** in Bambu Studio.

- Bambu Lab P2S, standard 0.4 mm nozzle, Generic PLA, Textured PEI.
- One connected part on one 256 × 256 mm plate.
- Part envelope: approximately **240 × 224 × 48 mm**.
- Flat bonding area: **110 × 116 mm**, centered on X=0, Y=0, top Z=6.
- Print estimate: **6 hours 4 minutes / 185 g PLA**, including support and brim.
- Actual extrusion footprint including brim/support: approximately **245.3 × 229.3 mm**, inside the 256 × 256 bed.

## Flat center

The center is a solid 6 mm plate, level with the arm roots. It has **no Jetson posts, edge stops, screw holes, bench bosses or ribbon slot**. Its full deck is 116 × 116 mm; the camera mount at the nose leaves a centered 110 × 116 mm rectangle completely unobstructed. Glue your existing tray to this surface, with the Jetson centered between the motors.

Your measured tray footprint is **95 × 111 mm**. Orient it with 95 mm along X (front to rear) and 111 mm along Y (left to right), centered at (0,0). This leaves 7.5 mm per end and 2.5 mm per side within the flat rectangle. Its thickness, board support height and adhesive are unmeasured; the complete fit and attachment have not been physically validated. The Jetson CAD reference is shown at a **provisional PCB underside height of Z=14**, assuming 8 mm lift above the deck. It is a placement reference, not a model of your tray. Check the real tray and board against the camera bracket, connector access and propeller sweeps before bonding. The frame provides a bonding surface for the tray; it does not directly support a bare Jetson PCB.

The four arms now taper from **28 mm-wide rounded roots to 20 mm-wide ends**, replacing the earlier 16 mm arms. Their thickness remains 6 mm, level with the deck, and motor mounting height and screw engagement are unchanged. The wider roots add material at the deck joints; structural strength and vibration performance have not been physically tested. The four motors, small-board mounting tabs and braced camera mount remain. The camera stays forward-facing at 0°, with two 3 mm triangular braces and an open window. No guards or canopy are included.

## Print

1. Open the supplied 3MF as a project and keep its placement. **Do not auto-arrange**: the centered part's actual brim and support toolpaths have been checked against the bed. Keep scale at 100%.
2. Confirm P2S, standard 0.4 mm nozzle, Generic PLA and Textured PEI. This is one single-color job; no AMS is needed.
3. Embedded settings: 0.24 mm layers, 0.20 mm first layer, four walls, 100% rectilinear infill, four top/bottom layers, 3 mm outer brim and automatic organic tree supports. The integrated motor pads remain solid.
4. Starting profile temperatures are 220°C nozzle / 55°C bed. Match the actual filament and re-slice if changing settings. Review the sliced preview before printing.
5. Cool the plate before removal. Remove the brim and camera supports and clear the mounting bores.

No print has been sent to a printer.

## Mount the hardware

X is forward, Y left and Z up. The bottom face is Z=0.

| Component | Position / interface | Hardware |
|---|---|---|
| Four motors | Centers (±104, ±96); 11.5 × 11.5 pattern; Ø3.4 holes; 6 mm pads | Four M3 screws per motor from below. Length = pad thickness + measured safe engagement. |
| Existing 95 × 111 Jetson tray | Centered 110 × 116 flat area, top Z=6 | User-supplied tray and adhesive; no printed Jetson mounts. |
| ESC | Center (0,-75); 20 × 20 pattern; nominal PCB underside Z=10 | M2 through bolts, supplied grommets and nuts; match length to actual stack. |
| Feather | Center (0,+73); 45.72 × 17.78 pattern; PCB underside Z=10 | M2 × 14 starting length, nuts and insulating washers; verify fit. |
| IMU | Center (-45,-73); 20.32 × 17.78 pattern; PCB underside Z=10 | M2 × 14 starting length, nuts and insulating washers; verify board revision. |
| B0249 camera | Mount front face X=58; optical center Z=26; 34 × 34 pattern | M2 × 8 starting length through 3 mm bracket; check the actual PCB, washers and nuts. |

**The old four M4 bench holes are removed.** The earlier 80 × 40 drilling pattern does not apply to this revision. Your manual fixture must restrain the frame through a separate attachment; the glued electronics tray is not a specified motor-test restraint.

Use the paired arm holes to tie motor wires. Route the camera ribbon around the edge of the flat deck; its former through-slot is removed. Secure external power strain relief to the bench base and leave slack to avoid pulling on the tray. Keep the fan and connectors clear. Provide space beneath the frame for motor screw heads and small-board nuts.

## Verification

The mesh export now shares vertices between adjacent triangles. This corrects a previous 3MF export that caused the slicer to fill holes. All 16 motor screw bores and four central relief bores are checked against the actual extrusion paths on every motor-pad layer, including after reopening and re-slicing. Use the file marked `Motor_Holes_Fixed`.

The automated report checks a valid single solid, watertight connected mesh, nominal component/prop/fan/camera/connector clearances and bed fit. It also verifies that the entire 110 × 116 mm bonding rectangle contains solid material below Z=6 and no raised features above it. Saved FreeCAD parameter edits and the Bambu project's re-slice are checked separately.

The supplied 95 × 111 mm tray footprint fits the flat rectangle. These checks do not validate its unmodeled height and details, adhesive, actual assembled balance, physical fit, temperatures or strength. Keep the restrained bench-demo use and physical hardware checks from the previous design: motor screw engagement, wiring clear of props, actual installed blade height, camera depth and PLA performance remain to be checked on hardware. The camera depth and propeller Z envelope are provisional allowances.

## Files and rebuilding

- `Corvidia_Compact_P2S_PLA_Motor_Holes_Fixed.3mf`: prepared Bambu print project.
- `Corvidia_Compact.FCStd`, `.step`, `.stl`: CAD and geometry exports.
- `geometry_checks.json`, `print_checks.json`, `reopen_check.json`, `editability_check.json`: current verification records.
- `preview.png`, `first_layer.png`, `toolpaths.png`: current slice previews.

Run `cad/Open_Compact.FCMacro` from the workspace to load the FreeCAD Python definitions and open the editable parameter sheet. Rebuild with `cad/compact_frame.py`, `cad/slice_compact.py`, then `cad/check_compact.py`. A full rebuild uses the original manufacturer references retained in the workspace. The Jetson reference height can be adjusted with `JetsonGap` in the source defaults and rebuilt after your tray is measured.

Profiles derive from [Bambu Studio 2.8.2.61](https://github.com/bambulab/BambuStudio/releases/tag/v02.08.02.61), retaining the official P2S machine routines. The official end routine includes `T65535`; the CLI logs it as an invalid T command while completing the slice successfully. Machine G-code has not been altered.

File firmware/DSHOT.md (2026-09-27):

# DShot300 + IMU bench firmware

This page records the v4 design and commissioning. The current v5 source adds
operator-selectable envelopes; see [DSHOT_V5.md](DSHOT_V5.md) for its limits,
protocol and installation status. V4's verified physical test range remains
5% input for 500 ms.

The driver runs in the STM32 firmware. MAVLink carries commands and telemetry
between the host and STM32; the ESC keeps its AM32 firmware.

```text
Jetson / host -- MAVLink --> STM32 -- DShot300 --> ESC --> motors
```

## Current stage

The integrated source includes BNO085 attitude/gyro telemetry and bounded,
operator-only individual and simultaneous all-four motor commands. It does not run a flight controller, mixer,
position hold, or LLM movement requests. The `feather_f405_dshot_imu_signal`
zero-throttle image has now been flashed with ESC battery disconnected; all
59,132 payload bytes match the DFU readback. The board boots and reports
`DS_OUTPUT=1`, `DS_ALLOW=0`, `DS_FAULT=0`, and zero requested input on every channel.
The first 15-second capture contained no ATTITUDE packets and reported
`IMU_OK=0` with both age fields `-1`: IMU initialization failed. A full USB power
cycle produced the same result. A second zero-only build is now installed with a
startup delay, probes for both documented sensor addresses, initialization-stage
telemetry, restoration of 400 kHz after the library resets the bus to 100 kHz,
and DShot timer startup after IMU initialization. Its 59,404-byte payload matches
the DFU readback. It boots and identifies the sensor at `0x4A` with `IMU_INIT=5`,
but the accepted reports become stale. The installed image is now the
`feather_f405_dshot_imu_bench` v4 build: it includes the sequence-based freshness
fix and both individual and all-four tests. All 59,740 payload bytes match the
DFU readback. A 15-second live check received 749 ATTITUDE and 749 quaternion
packets (about 50 Hz each), fresh attitude/gyro ages of 2/1 ms, `IMU_REJ=0`,
`DS_FAULT=0`, `DS_ALLOW=1`, `DS_ALL=1` and zero requested input on every channel.
Each motor passed an individual 1% input (DShot 67), 200 ms test. After those
checks, the same pulse was sent to all four together. Test and stop commands were
acknowledged each time; the operator confirmed the correct motors spun smoothly
and stopped after all five pulses. See the [powered test record](../docs/references/control/dshot-powered-tests-2026-09-27.md).
A subsequent all-four test at 5% input for 500 ms also passed operator-observed
smooth motion and complete stop, with healthy IMU telemetry and zero final inputs.
These observations do not verify RPM, signal waveform timing, sustained operation,
fault recovery or flight control. The original firmware backup remains available.

The old PWM host tool remains blocked after the
[motor-4 stop failure](../docs/references/control/motor-session-2026-09-27.md).
DShot commissioning requires explicit readiness for each invocation, fresh
firmware/IMU readiness and zero reported input on all four channels. Simultaneous
execution additionally requires confirmation of the four individual physical
stop checks. These checks are operator observations, not RPM telemetry.

The user asked to treat the setup as if propellers were installed. Props were
confirmed removed, motors secured, and startup stationary before the first test.
A throttle cap is not an RPM limit: motor speed and physical stop are not measured.

## Build profiles

| Environment | IMU | ESC output | Nonzero commands |
| --- | --- | --- | --- |
| `feather_f405` (repository default) | Yes | None | Rejected |
| `feather_f405_dshot_imu` | Yes | Pads held low | Rejected |
| `feather_f405_dshot_imu_signal` | Yes | Zero DShot frames | Rejected |
| `feather_f405_dshot_imu_bench` | Yes | Bounded DShot | Explicit enable required |
| `feather_f405_dshot_diagnostic` | No | Pads held low | Rejected |
| `feather_f405_dshot_signal` | No | Zero DShot frames | Rejected |

The bench profile explicitly sets `CORVIDIA_DSHOT_SIGNALS=1`,
`CORVIDIA_DSHOT_BOUNDED=1`, and `CORVIDIA_DSHOT_MOTOR_TESTS=1`. It exists for
validation; a successful build does not approve powered use. No profile arms
for flight. The old PWM bench profile and host protocol remain separate.

## Command bounds and stop conditions

- Individual tests select one ESC channel; the other three receive zero.
- An explicit all-four command applies the same bounded input to all four
  channels with one shared duration and stop deadline. Both modes are present
  in the same bench image; changing modes does not require another flash.
  Run the individual motion and physical-stop checks before using all-four mode.
  The firmware cannot independently certify those physical checks.
- Input greater than 0 and at most **5%**; duration **20–500 ms**.
- Host dry-run defaults: **1% input, 200 ms**. No ramp, calibration, reversing,
  or reserved DShot setting commands are exposed.
- Percent input maps to `48 + floor(1999 * percent / 100)`: 1% is DShot 67,
  5% is 147. This does not predict RPM; even low inputs may spin quickly.
- Three-second boot gate after IMU initialization, then a fresh operator
  heartbeat and healthy attitude AND gyro are required to enable a test.
- Each enable uses a new token and lasts at most three seconds. One test consumes
  the enable. Retried commands cannot restart or extend that test.
- The timer checks the fixed run deadline, a **50 ms** main-loop refresh limit,
  **100 ms** age limits for each IMU report and a **500 ms** operator-heartbeat
  limit. A late refresh cannot revive an expired test.
- Stop/disarm, unhealthy IMU, a reported IMU reset, or an expired deadline cancels
  the test. Starting again requires a fresh enable/token.

TIM5 runs the frame service at 1 kHz independently of the main loop. On expiry it
continues sending zero frames. Deadlines take effect on the next timer service
and frame, subject to interrupt latency. Blocking I2C with interrupts still
running does not extend the run. Globally masked interrupts, CPU/clock failure,
DMA failure and physical ESC behavior remain hardware validation concerns.
DMA errors latch an output fault and force pads low; that fallback depends on
the ESC's unverified signal-loss behavior. A stop ACK is not proof of stopped motors.

## IMU integration

BNO085 runs over I2C at 400 kHz. Game rotation vector and calibrated gyro reports
are requested at 200 Hz. Game rotation vector avoids magnetometer correction;
its yaw is relative and can drift. This changes the shared IMU wrapper used by
the default source image too. The newly installed zero-throttle diagnostic uses
this wrapper. V4 passes the IMU freshness check after the v1 initialization
failure and v2 timestamp-filter failure.

The wrapper tracks attitude and gyro arrival times separately, rejects invalid
values and duplicate/out-of-order report sequence numbers, normalizes valid quaternions,
and clears health on a sensor reset. Each update handles at most four reports.
The underlying library may block within one transaction; the motor timer is
separate. Freshness uses receipt time and report sequence progression, not an
independently synchronized measurement of sensor capture latency.

The v3 source fixes a live-test finding: Adafruit's I2C HAL does not populate
its `t_us` output, so SH-2 reconstructed timestamps cannot serve as the monotonic
sample clock assumed in v1/v2. The wrapper now uses the documented 8-bit report
sequence with wrap handling and retains separate MCU receive-time deadlines.
Reference: [Adafruit I2C implementation](https://github.com/adafruit/Adafruit_BNO08x/blob/master/src/Adafruit_BNO08x.cpp),
[SH-2 report sequence definition](https://github.com/adafruit/Adafruit_BNO08x/blob/master/src/sh2_SensorValue.h).

The integrated image sends ATTITUDE and ATTITUDE_QUATERNION at a target 50 Hz
while both reports are fresh. USB backpressure can reduce telemetry rate; old
telemetry is not queued indefinitely. The quaternion is the sensor frame;
mounting rotation and body-axis alignment are still unverified. A failed initial
IMU setup requires investigation/restart and never enables a motor test.

## MAVLink interface

Board IDs: system/component `1/1`. Operator IDs: `255/190`, with GCS heartbeats.
Only exactly addressed COMMAND_LONG packets are processed. Source filtering is
not authentication; this bench interface assumes a trusted local USB connection.
Heartbeat custom mode is `0x4453494D` (`DSIM`); the zero-only diagnostic remains
`0x44533330` (`DS30`). Flight arming stays disabled even during a bench test.

| Command | Parameters 1–7 |
| --- | --- |
| USER_1 / 31010: enable | `1, token, 0, 0, 0, 0, 0` |
| USER_1 / 31010: stop | `0, 0, 0, 0, 0, 0, 0` |
| USER_2 / 31011: individual test | `motor (1–4), percent, duration_ms, token, 0, 0, 0` |
| USER_3 / 31012: all-four test | `4, percent, duration_ms, token, 0, 0, 0` |
| COMPONENT_ARM_DISARM: stop | `0, 0, 0, 0, 0, 0, 0` |

Read the next token from `DS_TOKEN` before enabling, and use that same token for
the test. Accepted enables increment the next token. Tokens are single-use within
one boot and are not a security credential; never replay queued requests across a
reboot. Enable/test packets require `confirmation=0`; clients must not retry on
ACK loss. Timeout recovery sends stop and requires a new explicit test.

DO_MOTOR_TEST (the old PWM command), arming, and autonomous setpoints are not
accepted by the integrated image. Custom USER commands keep percent input,
DShot values, PWM microseconds and RPM from being confused.

All-four operation uses a distinct command; invalid individual motor IDs never
select all motors. The host requires a fresh `DS_ALL=1` capability report for an
all-four test, so older firmware cannot be mistaken for an image supporting it.
This capability flag does not certify physical motor behavior.

NAMED_VALUE_INT reports include `IMU_OK`, `ATT_AGE`, `GYR_AGE`, `DS_OUTPUT`,
`DS_ALLOW`, `DS_ALL`, `DS_FAULT`, `DS_TOKEN`, `DS_ACTIVE`, `DS_EXPIRE`, `DS_FRAMES`, and
`M1_DS` through `M4_DS`. The second diagnostic image also reports `IMU_INIT`
(0 not attempted, 1 no address, 2 both addresses, 3 sensor handshake failed,
4 report setup failed, 5 configured), `IMU_ADDR` and `I2C_MASK` (bit 0: 0x4A,
bit 1: 0x4B). V4 also reports raw report counters `IMU_ATT`, `IMU_GYR` and
rejection count `IMU_REJ`. Status rotates at 25 packets/s (each field roughly every 0.88 s
with these diagnostics); it can miss a short motor pulse. Inputs are requested values, not measured
RPM. Frame counts record completed DMA transfers, not ESC acknowledgements.
The read-only IMU dashboard recognizes the new image and displays these fields.

## Pins and resources

| ESC input | Feather pin | Timer channel |
| --- | --- | --- |
| 1 | 9 / PB8 | TIM4 CH3 |
| 2 | 10 / PB9 | TIM4 CH4 |
| 3 | 6 / PC6 | TIM3 CH1 |
| 4 | 5 / PC7 | TIM3 CH2 |

The user confirmed this rewiring and installation. Actual channel-to-motor
response still needs verification. No additional rewiring is prescribed.

Timer DMA bursts use DMA1 stream 2/channel 5 for TIM3 and stream 6/channel 2 for
TIM4. Transfers are non-circular and finish with low tails. The integrated image
also owns TIM5. It does not link the PWM driver, NeoPixel output, or flight mixer.
Current Wire calls do not use DMA; review these resource assignments before
adding DMA-backed I2C or other peripherals.

## Build and checks

Local validation on September 27, 2026: all three integrated profiles, the
default IMU image and both original DShot diagnostic profiles built successfully.
The latest bench/signal/interlocked builds pass. All 57 native C++ tests and
28 Python tests passed; the dashboard JavaScript
passed syntax checking. Firmware builds still emit warnings from vendored
MAVLink packed-member helpers. Dashboard rendering and hardware behavior have
not been verified for this integration.

From the repository root:

```sh
pio run -d firmware -e feather_f405_dshot_imu -e feather_f405_dshot_imu_signal -e feather_f405_dshot_imu_bench
pio test -d firmware -e native
.venv-control/bin/python -m unittest discover -s firmware/tools -p 'test_*.py' -v
.venv-control/bin/python firmware/tools/dshot_motor_test.py --motor 1 --percent 1 --duration-ms 200
.venv-control/bin/python firmware/tools/dshot_motor_test.py --all-motors --percent 1 --duration-ms 200
```

The final two commands only print plans and do not open serial. `--motor` and
`--all-motors` are mutually exclusive. Individual mode remains the default.
To execute a bounded DShot commissioning request, add `--port PORT --execute
--bench-ready` after confirming props are removed, motors secured, startup
stationary and hands clear. All-four mode additionally requires
`--individual-stops-checked` after observing each motor's correct motion and stop.
The old PWM tool's incident interlock remains disabled and is not shared with
DShot commissioning. Stop-only execution is available for the correctly
identified integrated image. No motor command is automatically retried.

Hardware checks remain: with ESC battery disconnected, measure DShot bit timing,
packet contents, zero tails and channel routing while the IMU runs. Exercise
command/heartbeat/IMU/main-loop timeouts and reset behavior on the output signals.
Record physical motion and stop after each powered pulse; an ACK only confirms
firmware command acceptance.

References: [DShot specification](https://betaflight.com/docs/wiki/guides/current/Dshot),
[MAVLink common commands](https://mavlink.io/en/messages/common.html),
[STM32F405 timer/DMA mapping (ST manual excerpt)](https://betaflight.com/assets/files/stm32f405_pins_timers_dma-e7ae8fce49c50af781149b0458e4ac87.pdf).

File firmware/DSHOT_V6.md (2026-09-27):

# DShot + IMU v6: fixed five-second startup ramp

**Status: deferred, not installed or verified with powered motors.** This
document describes a prepared, opt-in firmware profile. The STM32 and the
active Jetson mission adapter remain on v5, which has immediate input rather
than this ramp. The prepared v6 host changes were archived outside this
checkout; building this profile does not enable v6 support in the current app.

The `feather_f405_dshot_imu_ramp` profile extends the bounded v5 bench image
with a fixed startup ramp. It identifies itself as `DSI6` (`0x44534936`),
reports `FW_REV=6`, and advertises `DS_RAMPMS=5000` over MAVLink.

Every accepted individual or all-four run starts at zero input and rises to
the requested target over five seconds. The ramp uses only valid throttle
codes 48–2047; it never emits ESC setting commands 1–47. At a 25% target,
the commanded values are approximately:

| Time after start | DShot input |
| --- | --- |
| 0 | 0 |
| 1.25 seconds | 172 |
| 2.5 seconds | 297 |
| 3.75 seconds | 422 |
| 5 seconds onward | 547 |

These values describe requested motor input, not measured RPM, current, or
power. A ramp does not establish that a power supply can sustain the final load.

## Timing and stopping

The five seconds are included in the original run duration. A 30-second mission
ramps for five seconds and can hold its target for the remaining 25 seconds.
A shorter run can end before reaching the target. Confirmed first-match
missions can still end during the ramp.

Stop, expiry, main-loop timeout, IMU timeout, and heartbeat timeout bypass the
ramp and command zero immediately. The timer interrupt checks these limits
before calculating ramp progress. Late refreshes cannot revive an expired run;
duplicate starts cannot restart the ramp or extend its deadline.

## Protocol and compatibility

The v5 enable/start/stop packet shapes and single-use tokens are unchanged.
There is no packet field to disable or shorten the ramp. A corresponding v6
host adapter must require the v6 identity, revision, and fresh
`DS_RAMPMS=5000` before enabling hardware. That adapter was prepared but is
not active: the current Jetson mission adapter requires the v5 identity and
rejects v6.

`feather_f405_dshot_imu_bench` remains the installed v5 profile with immediate
input. Do not assume a startup ramp when using that profile. Activating v6
requires a coordinated host update, firmware installation, and separate
verification; none of these steps happens when committing or building the code.
The new profile selects `CORVIDIA_DSHOT_RAMP_MS=5000`; only values 0 and 5000
are supported at compile time.

## Build and verification

```sh
pio test -d firmware -e native -e native_ramp
pio run -d firmware -e feather_f405_dshot_imu_ramp
```

The prepared v6 firmware passed 92 C++ tests. The 715 Jetson tests were run
against the prepared v6 host tree, not the current v5 host checkout. After
restoring the v5 host, its focused validation passed 197 tests. These results
do not establish v6 installation or powered behavior.

The prepared payload is 60,436 bytes with SHA256
`5c4ae7fe919db31f53eb0b3ac0ec7124a84e0b16bdb118db9969821d4946a3fc`.
The DFU-suffixed file is 60,452 bytes. Installation and powered verification
must be recorded separately; successful tests alone do not establish either.

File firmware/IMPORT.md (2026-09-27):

# STM32 firmware import

Imported September 27, 2026 from `Downloads/firmware.zip`.

This document records the original import. Subsequent motor-control work and
updated build verification are documented in [MOTOR_CONTROL.md](MOTOR_CONTROL.md).

Archive SHA-256:
`e570d3e84341beb07cd30e58c8f743a515f548436511a1adefb289b64aed8221`

## Included

- PlatformIO project for the Adafruit Feather STM32F405 using STM32duino.
- BNO085 polling: rotation vector and calibrated gyro, requested at 200 Hz.
- USB CDC MAVLink transport: 1 Hz heartbeat and 50 Hz attitude/active-setpoint telemetry.
- Heartbeat watchdog, command arbiter, PID module, and rate timer.
- Four native Unity test suites and the original IMU visualization utility.
- Vendored MAVLink headers and the original editor extension recommendations.

At import, firmware source, configuration, headers, tests, and tools were copied unchanged.
The archive's `.pio/` build/dependency cache and macOS `__MACOSX` metadata are
excluded. The source archive remains in Downloads.

## Current behavior and documentation differences

The original README describes Phase 0 text output; `src/main.cpp` contains the
later MAVLink implementation. **USB CDC now carries binary MAVLink**, so the
README's sample text output and `tools/imu_viz.py` text parser do not describe
the current wire protocol. The referenced `docs/ARCHITECTURE.md` and Jetson
`mavlink.monitor` module were not supplied with this archive or the merged
perception branch.

The code polls the IMU and selects/echoes command setpoints. It does not yet
connect the PID to a motor mixer or implement ESC outputs. The arbiter's fixed
0.30 thrust fallback is a software setpoint, not a demonstrated descent behavior.

The imported driver requests `SH2_ROTATION_VECTOR`, not the game rotation vector
proposed in the Scout architecture. IMU health uses one combined freshness
timestamp for attitude and gyro. These are existing implementation details;
the import does not change the control or sensor behavior.

## Import verification

All 17 existing native test cases passed on macOS using Clang and the Unity
sources supplied in the archive, with empty `setUp`/`tearDown` hooks:

| Suite | Passed |
| --- | ---: |
| Command arbiter | 6 |
| Link watchdog | 3 |
| MAVLink round trip | 4 |
| Rate timer | 4 |

PlatformIO and the ARM compiler were not installed in this environment, so an
STM32 target build and hardware/IMU verification were not performed. With
PlatformIO installed, the project's intended commands from `firmware/` are:

```sh
pio test -e native
pio run -e feather_f405
```

No firmware was flashed during this import.

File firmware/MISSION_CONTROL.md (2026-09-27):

# Mission control candidate

## Current result

The software now accepts an operator-selected mission duration and motor ceiling
up to 1.0 (100% normalized command). Nominal collective is a separate setting,
defaulting to 0.5 as requested. It must be below the ceiling to leave room for
attitude corrections. Neither value measures electrical power, RPM or lift.

This is a host-tested candidate, not the final flight firmware. The installed DShot v5 bench image defaults to the verified 5% / 500 ms
envelope and supports larger explicit operator envelopes; see [DSHOT_V5.md](DSHOT_V5.md). No mission packets were transmitted or ESC settings changed during mission
candidate development. The later v5 installation only changes the bench interface. Increasing those bench limits would not produce a flight controller.

## Ownership

| Component | Owns |
| --- | --- |
| Operator | Start/stop authority, mission duration, output ceiling, commissioning |
| LLM | Bounded movement proposals or `stop_mission` |
| Jetson supervisor | Validate proposals, current perception/state checks, session and sequence IDs, timely updates |
| STM32 flight layer | Fresh IMU, body-frame controller, mixer, output bounds and validated flight fallback |

The LLM cannot set throttle, arm, extend a mission or send keepalives through its
intent schema. A deterministic supervisor must re-evaluate state before issuing
each new movement. Repeating cached LLM output with new sequence IDs is not a
valid substitute for that evaluation.

## Implemented software

- `include/mission_session.h`: operator session with immutable duration, nominal
  collective and ceiling. Session IDs cannot repeat within a receiver lifetime.
  No demand exists until a valid movement is accepted.
- `include/mission_control.h`: session → attitude/rate controller → quad mixer.
  Unverified gains/layout, stale IMU or invalid controller output invalidate the
  result and latch a fault. Controller history resets between sessions.
- `include/mission_protocol.h`: candidate MAVLink COMMAND_LONG begin/action
  decoder. It checks target, source role, finite values, exact integers, unused
  fields, bounds, session and action sequence.
- `tools/mission_request.py`: offline packet generator and intent validator.
  It has no serial or execution option.
- `mission-intent.schema.json`: movement or mission-stop intent, without power
  or authority fields. Operator settings live in `mission.example.json`.

### Timing

| Limit | Candidate value |
| --- | --- |
| Mission duration | Operator-selected 1–1,800,000 ms (30-minute software bound) |
| Movement duration | 1–1,000 ms |
| Trusted supervisor lease | 250 ms; suggested update interval 50 ms |
| Tilt / yaw-rate request | At most 10 degrees / 30 degrees per second |

Keepalives do not extend a movement or mission. Once a movement expires, this
candidate ends the session; a late update cannot resume it. During a longer
mission the supervisor must submit new valid movements before the active action
expires. A fresh action does not refresh the independent supervisor lease.

`stop_mission`, deadline expiry or loss of supervision revokes mission authority.
**An invalid motor frame means flight fallback is required; it is not an
instruction to write zeros to airborne motors.** That fallback is not implemented
here. No fixed throttle can be labeled a controlled descent. The legacy arbiter's
fixed 0.30 descent output is not used by this candidate.

## Packet contract (candidate only)

All packets target system/component 1/1 with confirmation 0. IDs and sequence
values are at most 16,777,215 for exact representation in COMMAND_LONG floats.

| Command | Sender | Parameters 1–7 |
| --- | --- | --- |
| USER_5 / 31014 begin | Operator 255/190 | session ID, nominal collective, ceiling, mission duration ms, 0, 0, 0 |
| USER_4 / 31013 action | Supervisor 42/191 | action code, amount, duration ms, session ID, sequence, 0, 0 |

Action codes: level=0, forward tilt=1, backward tilt=2, left tilt=3, right tilt=4,
left yaw=5, right yaw=6. Tilt uses degrees; yaw uses degrees per second.
These are attitude requests, not velocity/position guarantees. “Level” is not hover.

Local `refresh()` and `stop()` operations exist, but their transport handling is
not implemented. Neither installed firmware image dispatches these mission
commands. Session negotiation after reboot, receipt ACKs/status, authenticated
operator authority, supervisor lease transport and airborne fallback must be
finished before connecting this contract to flight outputs. MAVLink source IDs
alone provide no authentication.

MAVLink defines the command container and fields; these USER commands are our
application contract, not standard PX4 flight commands. See the
[MAVLink common definitions](https://mavlink.io/en/messages/common.html#COMMAND_LONG).
PX4's [offboard control documentation](https://docs.px4.io/main/en/flight_modes/offboard)
also distinguishes continuing control updates from link-loss handling; this
project uses its own receiver and must implement its own fallback.

## Run the offline preview

From the repository root:

```sh
.venv-control/bin/python firmware/tools/mission_request.py \
  --settings firmware/mission.example.json \
  --intent '{"action":"tilt_forward","amount":4,"duration_ms":500}'
```

The output includes packet bytes for inspection, `execution_available: false`
and a requested attitude. Example settings are a 60-second mission, nominal
collective 0.5 and motor ceiling 1.0. They are not flight calibration.

## Hardware facts and remaining work

The user confirmed the mounted positions, viewed from above with the camera forward:

```text
                  camera / forward
          4 front-left      2 front-right
          3 rear-left       1 rear-right
```

The user subsequently confirmed the positions remained unchanged and rotation
now matches the selected pattern: 1/4 clockwise, 2/3 counterclockwise, viewed
from above. The method used to correct rotation was not specified. The observed
rotation check is complete; the software candidate records the resulting yaw
signs but keeps flight integration gated pending body-axis and controller checks.
See [the direction record](../docs/references/control/motor-directions-2026-09-27.json).

Before flight-output integration:

1. Rotation and positions are confirmed by the user. Match eventual propeller
   handedness to those directions; keep props removed during current checks.
2. Dominant IMU axes have been measured as body X=−sensor X, Y=+sensor Y,
   Z=−sensor Z; software restoring-direction tests pass. Finish precise mounting
   alignment, absolute attitude conversion and deliberate gyro-motion checks.
   See the [axis-check record](../docs/references/control/imu-alignment/README.md).
3. Tune/validate rate and attitude gains. Test timing, CPU/IMU/link failures and
   independent motor-output deadlines with appropriate measurement and restraint.
4. Implement velocity/height estimation and vertical control. Static 50% collective
   does not hold height. No altitude/velocity feedback is currently connected.
5. Implement and verify pilot override and flight fallback (landing where sensing
   supports it), plus battery monitoring. A pilot-handoff label alone is not a
   working receiver/control path.
6. Complete mission transport and connect validated control to a separately
   supervised output driver. The bench DShot lease is not a mission actuator API.

Validation: all 66 native C++ tests and 35 Python tests pass. Added tests cover
fixed deadlines, stale supervision, action expiry, repeated/out-of-order requests,
session restart, clock wrap, fault latching, mixer/gain gates, role/target checks,
float packet bounds and Python MAVLink encode/decode. No flight validation is claimed.

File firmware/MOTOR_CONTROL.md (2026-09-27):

> **Legacy PWM testing remains stopped.** During the September 27 session the user
> reported sustained motor-4 rotation outside an active channel-1 test, despite
> acknowledged stop commands. Keep the ESC battery disconnected. PWM timing,
> channel mapping and the ESC stop setting must be verified before another
> PWM test. The PWM host CLI blocks spin requests before opening serial;
> dry runs and stop remain available. See [the session record](../docs/references/control/motor-session-2026-09-27.md).

# STM32 motor controls

## Current status

The installed image is [v5](DSHOT_V5.md), with IMU telemetry and bounded DShot
commands. The onboard mission demo uses 5% equal input with a 7.5% host cap;
see the [current console guide](../perception/STAND_DEMO.md). The optional
[v6 ramp](DSHOT_V6.md) is prepared but has not been installed. The sections
below retain the earlier v4 and PWM implementation history.

## Earlier v4 implementation

The [DShot300 integration](DSHOT.md) now combines IMU telemetry with bounded
MAVLink bench commands: individual or explicit all-four operation, at most 5%
input and 500 ms, plus independent
timer deadlines. Signal and motor-command interlocks default off. The combined
individual/all-four bench image (v4) was flashed and readback-verified. It
includes the IMU freshness fix; live IMU telemetry is about 50 Hz, both test
modes are available, startup input reports are zero, and stop is acknowledged.
Each individual motor and then all four together passed user-observed smooth
spin/stop checks at 1% input for 200 ms, followed by all four at 5% for 500 ms. See the [DShot test record](../docs/references/control/dshot-powered-tests-2026-09-27.md).
DShot requests require explicit bench readiness; all-four requests also require
individual physical stop checks. RPM and flight behavior are unverified. The PWM
bench and movement code below remain separate from it.

There are three separate pieces:

1. **Individual motor tests:** a dedicated STM32 firmware image and an operator
   CLI. One ESC output at a time, bounded pulse width and duration, explicit
   enable per test, heartbeat timeout, and an independent timer deadline.
2. **Movement proposals:** a strict JSON validator and matching C++ supervisor
   for level, bounded tilt, and yaw-rate requests. These are software previews.
3. **Controller and mixer:** host-tested angle/rate control math and an X-quad
   mixer. They require verified gains, fresh body-frame IMU values, a verified
   motor layout, and rotation directions. They are not connected to motor outputs.

The original `feather_f405` image continues to run the IMU/MAVLink application.
The legacy PWM bench image replaces that application while installed; it does not run
the IMU loop. No image here performs flight arming or autonomous flight.

## Corrected wiring

Disconnect the motor battery and USB before moving wires. Move only the
Feather ends of the two signal wires; leave all three phase wires per motor alone.

| ESC pad | Feather label | MCU pin / peripheral | Action |
| --- | --- | --- | --- |
| G | GND | Common signal ground | Keep |
| 1 | 9 | PB8 / TIM4 CH3 | Keep |
| 2 | 10 | PB9 / TIM4 CH4 | Keep |
| 3 | **6** | PC6 / TIM3 CH1 | Move from **11 to 6** |
| 4 | **5** | PC7 / TIM3 CH2 | Move from **12 to 5** |
| V | Disconnected | Battery voltage | Keep disconnected |
| C | A0, if used | PA4 / ADC | Optional; see below |
| T | RX, if used | PB11 / USART3 RX | Optional; see below |

Adafruit documents **no hardware PWM on D11/PC3 or D12/PC2**. D9/D10/D6/D5
have the timer channels listed above. SDA/PB7 and SCL/PB6 remain dedicated to the
IMU's I2C bus; sharing the TIM4 peripheral's other alternate-function pin options
does not require switching those I2C pins to PWM. Do not use `analogWrite()`
or servo pulse generation on D11/D12 as a substitute for this map.

The initial wiring had V disconnected and C/T connected. T was subsequently
disconnected for the DShot tests and current demo. The optional destinations
above are intended connections, not a verified observation of the actual wires.
C must be a current-sense output within the ADC's 0–3.3 V range. T must be a
compatible logic-level telemetry output. Their signal limits and the exact ESC
revision are not established by the supplied images; disconnect C/T for the
first test if these cannot be verified. This firmware does not read either pad.
With T attached, RX/PB11 is occupied by the ESC and cannot simultaneously serve
as the Jetson's UART RX. Keep the Jetson link on USB for now; TX is unused here.

The user has identified the ESC as a **Flywoo GOKU G45M 45A 3–6S AM32 4-in-1**.
See [the model investigation](../docs/references/control/ESC-G45M-AM32.md). The
installed settings and firmware version remain unknown. The PWM test profile requires ordinary
unidirectional RC PWM, with **1000 microseconds as stop**. A reversible/3D ESC
configuration may interpret that differently and must not use this profile.
Confirm the installed ESC configuration before enabling output. No automatic
full-throttle endpoint calibration is provided.

Battery positive/negative power only the ESC's battery pads. Never connect ESC
V/battery positive to Feather 3V, BAT, USB, or a GPIO. Use board silkscreen labels
and electrical continuity; the supplied generated diagrams have conflicting
arrows and duplicated/misaligned labels.

Sources: [Adafruit pinout](https://learn.adafruit.com/adafruit-stm32f405-feather-express/pinouts),
[STM32duino Feather variant](https://github.com/stm32duino/Arduino_Core_STM32/blob/main/variants/STM32F4xx/F405RGT_F415RGT/variant_FEATHER_F405.h),
[HardwareTimer API](https://github.com/stm32duino/Arduino_Core_STM32/wiki/HardwareTimer-library).

## Planned motor layout

View from above, camera looking toward the top of this diagram. This matches
the user's statement that 1/3 are rear and 1/2 are right when looking forward
from behind the camera.

```text
                   CAMERA / FRONT
           ESC 4                     ESC 2
           front-left                front-right

           ESC 3                     ESC 1
           rear-left                 rear-right
```

`include/airframe.h` stores these planned positions. The user has confirmed all
four motors are mounted or clamped for testing. Final frame positions and
rotation directions have not been physically verified. Consequently `verified=false`
and all yaw signs are unset. The mixer rejects that configuration. Host tests
use an explicitly synthetic rotation pattern, not a measured configuration.

## Build and tests

From `firmware/`, with PlatformIO installed:

```sh
pio test -e native
python3 -m unittest discover -s tools -p 'test_control_tools.py'
pio run -e feather_f405                  # existing IMU/MAVLink image
pio run -e feather_f405_bench            # bench protocol, all output disabled
pio run -e feather_f405_bench_pwm        # explicit PWM-capable bench image
```

The platform is pinned to `ststm32@20.0.0`. The PWM-capable image starts at
1000 us on every channel; starting a motor additionally requires an accepted
operator enable and test command. The default project environment remains
`feather_f405`; it has no ESC output code.

On September 27 the installed firmware was backed up with two matching full-flash
reads. The PWM bench image was flashed and its 36,464-byte payload verified by
DFU readback. A powered channel-1 test (1020 µs, 0.5 seconds) and stop were
acknowledged; see [the session record](../docs/references/control/motor-session-2026-09-27.md)
for physical observations and subsequent results. Compilation and host
tests do not verify pulse timing, electrical wiring, actual stop behavior,
rotation direction, or stabilization. Measure the outputs before the first
powered test. An oscilloscope/logic analyzer should show 50 Hz frames and only
1000 us stopped pulses; this is the ESC **input** frame rate, distinct from its
internal motor PWM frequency.

## Operator motor test

The user confirmed propellers are removed, all four motors are mounted or clamped,
and the corrected signal wiring has been completed. Electrical continuity and
ESC PWM configuration have not been independently measured. Check the PWM
configuration above before selecting the PWM build. Do not flash with the motor battery connected.

When ready, flash the selected bench image using the board's documented DFU
procedure and PlatformIO `pio run -e feather_f405_bench_pwm -t upload`.
For this board Adafruit documents holding BOOT0 high (3.3 V) while resetting to
enter the ROM DFU bootloader; remove that connection/reset for normal operation.
The original imported README's double-tap instructions are not relied on here.
See [Adafruit DFU instructions](https://learn.adafruit.com/adafruit-stm32f405-feather-express/dfu-bootloader-details).
Disconnect ESC T from Feather RX while entering/flashing the USB bootloader:
Adafruit notes that serial traffic on RX can interfere with ROM bootloader selection.

Install the host tool dependencies into a virtual environment:

```sh
python3 -m venv .venv-control
.venv-control/bin/pip install -r tools/requirements-control.txt

# Default: print the requested test, without opening any serial port.
.venv-control/bin/python tools/motor_test.py --motor 1 --pulse-us 1050 --seconds 1

# Explicit operator-only execution, after the checks above.
# Replace the example port with the actual device; on Jetson it may be /dev/ttyACM0.
.venv-control/bin/python tools/motor_test.py --port /dev/cu.usbmodemEXAMPLE \
  --motor 1 --pulse-us 1050 --seconds 1 --execute --bench-ready

# Stop requires no bench-ready acknowledgement.
.venv-control/bin/python tools/motor_test.py --port /dev/cu.usbmodemEXAMPLE --stop --execute
```

The tool identifies the bench firmware before sending commands, checks ACKs,
keeps sending operator heartbeats, and sends stop on normal exit or interruption.
It never retries a test automatically. A 1050 us pulse may not start a given
motor; do not respond by blindly increasing limits or performing high-throttle
calibration. Acknowledge and investigate ESC configuration and waveform first.

### Enforced limits

| Check | Behavior |
| --- | --- |
| Explicit enable | Eight-second window; cannot be extended by duplicate enables |
| Test | One channel, 1000–1100 us, 20–2000 ms through the protocol |
| Test completes | Stop all channels and revoke enable |
| Operator heartbeat | Stop/revoke after 500 ms; a late heartbeat cannot resume |
| Main loop stalls | TIM5 guard requests stopped pulses after 100 ms; latches until another operator enable |
| Output frame | Stopped compare takes effect by the next 20 ms PWM frame |
| Invalid command | Reject non-finite values, fractional motor IDs, out-of-range pulses, multi-motor sequences, wrong targets |
| Flight arm/setpoint | Unsupported/ignored in bench firmware |

The timer guard depends on functioning interrupts and the MCU clock; it is not
an independent hardware safety device. The bench image deliberately avoids IMU
I2C calls and NeoPixel transfers. This bench stop policy is not a flight failsafe.

### Wire protocol

Use MAVLink over USB. Firmware ID is system 1/component 1; the operator is
system 255/component 190. Its heartbeat uses `custom_mode=0x42454E43` (`BENC`).
Messages from the existing Jetson onboard-computer identity cannot activate
bench tests. These IDs separate roles, not authentication; serial access must
remain with the trusted operator tool, not an LLM shell.

- `MAV_CMD_USER_1` (31010): param1=1 enables a bench test; param1=0 stops/revokes.
  All other parameters zero. This is a project-local use of the USER command.
- `MAV_CMD_DO_MOTOR_TEST` (209): channel 1–4, PWM throttle type 1, pulse in us,
  duration in seconds, motor count 1, board order 2, param7=0. Only this subset
  is supported; no sequences. See [MAVLink common commands](https://mavlink.io/en/messages/common.html#MAV_CMD_DO_MOTOR_TEST).
- `MAV_CMD_COMPONENT_ARM_DISARM` with param1=0 stops; flight arming is rejected.

## Movement interface for the future LLM supervisor

The LLM proposes one action; deterministic code validates it. Human authority,
collective thrust, output enable, gain configuration, and mode changes remain
outside that interface. Decision inference does not run the rate loop.
`motion.schema.json` describes the three fields the model may propose; a trusted
supervisor adds `sequence` before passing the envelope to `motion_request.py`
or the C++ supervisor. No motor-test, throttle, or arm tool is offered to the model.

| Action | Amount | Effect |
| --- | --- | --- |
| `level` | 0 | Roll/pitch target zero, yaw rate zero |
| `tilt_forward` / `tilt_backward` | 0–10 degrees | Negative/positive pitch target |
| `tilt_left` / `tilt_right` | 0–10 degrees | Negative/positive roll target |
| `yaw_left` / `yaw_right` | 0–30 degrees/second | Negative/positive body yaw rate |

Every request has a duration of 1–1000 ms and a supervisor-assigned unsigned
sequence number. The supervisor must stamp sequence and receipt time outside
the model; do not accept queued stale decisions after a reconnect. Fresh local
supervisor keepalives are needed within 250 ms. They are independent of slow
LLM generation; they must not extend the action's absolute lifetime.

Example (preview only, no motors or serial):

```sh
python3 tools/motion_request.py \
  '{"action":"tilt_forward","amount":5,"duration_ms":500,"sequence":1}'
```

There is no `hover`, `move_meters`, `climb`, or `land` option: the current system
cannot regulate position or altitude. `level` does not brake drift. Preview
output explicitly reports `execution_available=false`. The C++ supervisor
provides limits, replay rejection within a session, expiry, and revocation.
The angle controller produces rate targets, then bounded rate PID corrections;
the mixer converts them to normalized motor demands. These software components
are currently exercised in tests only.

Before connecting that path to actuators, verify motor rotation, IMU-to-body
orientation, separate timestamped gyro/attitude freshness, control-loop timing,
gains and saturation handling, independent pilot override, and the response to
sensor/link loss. The existing IMU driver combines gyro/attitude freshness and
does not yet satisfy those flight-controller requirements.

## Verification recorded September 27, 2026

- All three STM32 build environments above compiled successfully with PlatformIO.
- All 35 native C++ tests passed, including 17 original tests and 18 new tests
  for motor limits, deadlines, protocol validation, motion expiry, controller
  checks, and mixer signs.
- All 10 host-tool tests passed, including wire command ID consistency, wrong-firmware rejection, disabled
  outputs, lost ACK handling without retry, and explicit stop.
- Motor and movement CLI dry runs passed. No serial device was opened for these
  checks; no flash, motor spin, or powered hardware test was performed.
- Generated MAVLink headers produce packed-member alignment warnings during
  compilation. They are not treated as evidence of hardware validation.

## Unpowered PWM diagnostic

`feather_f405_pwm_diagnostic` is for investigating the September 27 stop failure.
**Keep the ESC battery disconnected throughout.** It continuously produces the
same nominal 1000 µs signal on all four pads and rejects all incoming commands
by discarding them. It never runs a throttle test. It identifies itself using
custom mode `0x50574D44` (PWMD), which the motor-test host tool will reject.

The main loop samples GPIOB input bits 8/9 and GPIOC input bits 6/7, corresponding
to Feather 9/10/6/5. It observes rising/falling edges and sends MAVLink
NAMED_VALUE_INT measurements (`M1_US`, `M1_PERIOD`, `M1_MIN`, `M1_MAX`, and
similarly for channels 2–4). A fresh nominal signal should be approximately
1000 µs high with a 20000 µs period. Sampling gaps over 50 µs invalidate the
current pulse measurement; missing or stale widths are reported as -1.

This is a GPIO-pad diagnostic using the MCU's own clock, not an independent
oscilloscope. It can reveal gross pulse-generation errors but does not verify
voltage levels, the physical ESC connection, the ESC protocol/settings, stop
behavior, or motor numbering. The dashboard shows these measurements when the
diagnostic image is running. Do not reconnect motor power based on these
measurements alone.

```sh
pio run -e feather_f405_pwm_diagnostic
```

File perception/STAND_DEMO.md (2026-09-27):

# Person-search stand demo

This demo joins the Jetson camera, YOLO, Cosmos, saved evidence, and the STM32's
bounded all-four motor interface. The operator describes a person's visible
appearance and submits one mission. The screen gives turning and
hold instructions; the operator turns the guarded stand using its external
handle. An ordinary search ends after its first confirmed, saved image. A timed
collection keeps saving matching captures until its deadline, then requests zero
motor input.
The Jetson owns the complete mission after Start. The Mac is an optional debug
and command terminal; the mission continues if that connection closes.

This is a stand demonstration. All four motors receive the same fixed demo
input. Guidance changes what the operator does with the stand; it does not send
flight-controller movement commands.

## Onboard operation

Use the
[maintenance terminal commands](#maintenance-terminal-commands) to inspect
status, watch guidance, explicitly submit another mission, or stop one. The
backend stays running when the terminal or SSH connection closes; the STM32
firmware remains v5. A future powered run requires fresh readiness confirmation.

To keep the camera GUI while freeing the GNOME desktop's memory, select the
optional **Corvidia console (Xorg)** session at login. It opens only a lightweight
window manager and the mission console, attaching to the already running backend.
See [installation and session selection](deploy/CORVIDIA_SESSION.md). The normal
Ubuntu session remains available from the same login menu.

## Launch the native console on the Jetson

Open a terminal on the Jetson desktop:

```sh
cd ~/corvidia/perception
./deploy/stand-console.sh
```

This opens the native `corvidia-console` window with a live camera view, person
appearance prompt, mission status, manual turn/HOLD guidance, saved-image result,
and explicit Abort. The Search & Rescue layout uses a **Mission brief** field
and **Begin search** button. Enter or keypad Enter submits through the same
validation and readiness checks as the button, without adding a newline or
duplicating an already pending request. Enter a visible description such as
**person wearing a red shirt**, or a timed brief such as **find as many people as
possible within 30 seconds**. There are no motor-input controls or separate
duration fields. The console shows the number of saved captures and the latest
saved image.

The sidebar shows camera and STM32 link freshness, IMU roll/pitch/yaw in the
sensor frame, and requested motor input. Missing or stale telemetry is unavailable;
requested input is not measured RPM. Observation mode explicitly labels simulated
motor input. Compact displays keep detailed status in a separate Details window.

The launcher starts the backend in observation mode if it is inactive. It keeps
an existing service running and refuses a mode mismatch. With an already running
service, `.venv/bin/corvidia-console` launches the same window directly. The
Jetson desktop Python environment needs Tkinter and Pillow for the window.

For a separately commissioned hardware-mode service, use
`./deploy/stand-console.sh --hardware`. It requires that service to be active
already and presents the five physical readiness checks for each mission. The
launcher never switches an observation service into hardware mode.
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

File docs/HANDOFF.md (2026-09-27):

# Corvidia — project handoff

As of 2026-09-27. Branch `perception` (5 commits ahead of `main`, plus uncommitted
step-4 work described in [Work in progress](#work-in-progress-uncommitted)).

Corvidia is a bench demonstrator: a 3D-printed quadcopter-style frame carrying a
Jetson Orin Nano and a CSI camera. The current software milestone ("Scout") is a
**camera-to-event person detection pipeline**: detect a person, track them across
frames, ask a local vision-language model (Cosmos Reason 2 2B) to confirm, and save
reviewable evidence. It produces observation records only — no flight control,
no motion decisions.

## Status at a glance
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

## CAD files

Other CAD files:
hardware/frame/output/Compact_P2S_PLA/Corvidia_Compact_P2S_PLA_Motor_Holes_Fixed.3mf
hardware/frame/references/P3766-P3768SKU4-P3767ENVELOPE.stp
hardware/frame/output/Compact_P2S_PLA/Corvidia_Compact.step
hardware/frame/output/Compact_P2S_PLA/Corvidia_Compact.FCStd
hardware/frame/output/Compact_P2S_PLA/Corvidia_Compact.stl

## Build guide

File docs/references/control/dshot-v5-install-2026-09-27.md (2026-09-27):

# DShot IMU operator-envelope v5 — September 27, 2026

Status: flashed and boot-verified, with all 60,356 payload bytes matching
readback. ESC battery remained disconnected during startup verification.

The user requested an integrated testing image with selectable power and timing,
then specified a maximum fixed duration of one minute for stand demos. No
autonomous-flight readiness is claimed. Defaults remain 5% / 500 ms; supported
explicit envelopes extend to 100% / 60,000 ms.

- Profile: `feather_f405_dshot_imu_bench`.
- New identity: `0x44534935`, `FW_REV=5`.
- Payload: 60,356 bytes.
- Payload SHA256: `87c9e755933a3fb99ad9016cecad8e66a3261b6400887ee6f1030f1b68069957`.
- DFU-suffixed file SHA256: `ed4ad4b1e56f6767d24a4192f2ad821ea6501bc479442877ddc209b965ab1d19`.
- Preserved image: `~/Documents/Corvidia-hardware-backups/2026-09-27/dshot-imu-operator-envelope-v5.bin`.
- Existing v4 image/readback and original 1 MB backups remain preserved.
- Validation: 70 C++ tests and 43 Python tests passed, dashboard JavaScript syntax
  checked, all three integrated firmware profiles built successfully.
- No nonzero motor command has been sent during v5 preparation.

See [the v5 interface](../../../firmware/DSHOT_V5.md).

The user confirmed DFU ready, ESC battery unplugged and T disconnected. A full
1 MB pre-flash backup was saved as `stm32-before-v5.bin`; its first 59,740 bytes
match the preserved v4 firmware exactly. Backup SHA256:
`274c26d3e8a492cb24cf4b726deb390d4d444ffd71fa9135e52a7db6ff69b7ac`.
Only internal-flash alt 0 was written; option bytes and OTP were not changed.

## Live startup verification

The [15-second capture](dshot-v5-startup-2026-09-27.json) received 749 ATTITUDE
and 749 quaternion messages, 579 named values, 20 heartbeats and zero bad
fragments. Identity is DSI5, FW_REV=5. IMU_OK=1, IMU_REJ=0, attitude/gyro ages
4/1 ms. DS_FAULT=0, DS_ACTIVE=0 and all four requested inputs zero.
DS_MAXP=100, DS_MAXMS=60000; the current envelope is DS_CAP_BP=500 (5%)
and DS_CAP_MS=500. FLT_READY=0, AXES_OK=0. A stop-only request was acknowledged
after capture. No nonzero command was sent during installation or this check.

## Initial powered commissioning

After startup verification, the user confirmed props off, motors secured, ESC
battery connected, startup finished with all motors still and hands/cables clear.
One all-four test at 5% for 1000 ms passed, followed by one at 7.5% for 1000 ms.
The user confirmed smooth rotation and complete stop after both. Each command
and stop was acknowledged; fresh zero-input telemetry was checked. No retries.
Final 15-second telemetry confirms IMU_OK=1, IMU_REJ=0, DS_FAULT=0, DS_ACTIVE=0,
all motor inputs zero, DS_TOKEN=3, and defaults restored (5%/500 ms).
These tests do not validate full power or a 60-second run. The battery was
requested disconnected after the tests. See the [powered session record](dshot-powered-tests-2026-09-27.md).

A subsequent user-requested all-four pulse at 50% for 200 ms was sent once after
fresh physical readiness confirmation. The user confirmed smooth rotation and
complete stop. Test/stop ACKs and fresh zero-input telemetry were received. This
short pulse does not validate sustained 50% operation or the maximum duration.

The next user-requested all-four test at 50% for 2000 ms also passed operator-
observed smooth rotation and complete stop. The host confirmed test/stop ACKs
and fresh zero inputs; final telemetry reports no output fault, healthy IMU,
DS_TOKEN=5 and default limits restored. No longer run is validated by this test.

Final requested commissioning run: all four at 20% for 10,000 ms. The user
confirmed smooth running for the full pulse and complete stop. Host ACKs and
fresh zero-input checks passed. Final telemetry: IMU healthy, no output fault,
all motor inputs zero, DS_TOKEN=6 and default envelope restored.

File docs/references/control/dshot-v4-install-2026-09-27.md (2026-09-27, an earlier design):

# DShot IMU bench v4 installation — September 27, 2026

The user requested individual and simultaneous all-four tests in one firmware
image, so passing the individual tests would not require another flash.

- Device: Feather STM32F405, USB serial `326738693533`.
- Profile: `feather_f405_dshot_imu_bench`.
- ESC battery disconnected; no motor command sent during installation.
- Payload: 59,740 bytes; full payload readback matches byte-for-byte.
- Payload SHA256: `18c85b8bcef311b02ff5a52f9f07f4b06c7bec3aea66aeca496cf4c279222eb1`.
- Build-file SHA256 including DFU suffix: `31023c7564f6cb471bdeaad10e5c4be9509b9a53ca8bf67b9202d445ca5c228b`.
- Backup/image/readback/manifest are stored in
  `~/Documents/Corvidia-hardware-backups/2026-09-27/`.
- Original installed firmware remains preserved in two matching 1 MB backups.

V4 includes the report-sequence freshness fix, individual USER_2 and explicit
all-four USER_3 commands. Both use the same enable-token, finite-duration,
heartbeat, IMU and main-loop deadlines. Startup does not automatically enable a
test. All-four capability is compiled into this image and needs no later reflash.

Validation before upload: three integrated profiles built successfully, 57 native
C++ tests passed, and 28 Python tests passed. Physical DShot waveforms, ESC
acceptance, RPM and motor-stop behavior are not established by those tests.

## Live check

The board booted after jumper removal and RESET. A 15-second read-only capture
received 749 ATTITUDE and 749 ATTITUDE_QUATERNION packets, about 50 Hz each.
The IMU is at 0x4A, configured, with fresh attitude/gyro ages of 2/1 ms and zero
rejected reports. DShot reports no DMA fault; both DS_ALLOW and DS_ALL are 1.
DS_ACTIVE and all four requested motor inputs are zero. A stop-only command was
acknowledged afterward. ESC battery remained disconnected throughout.

Evidence: [live capture](dshot-imu-bench-v4-live-2026-09-27.json).
No nonzero motor command or powered motor test was performed in this check.
Physical waveforms, RPM and stopping still require verification.

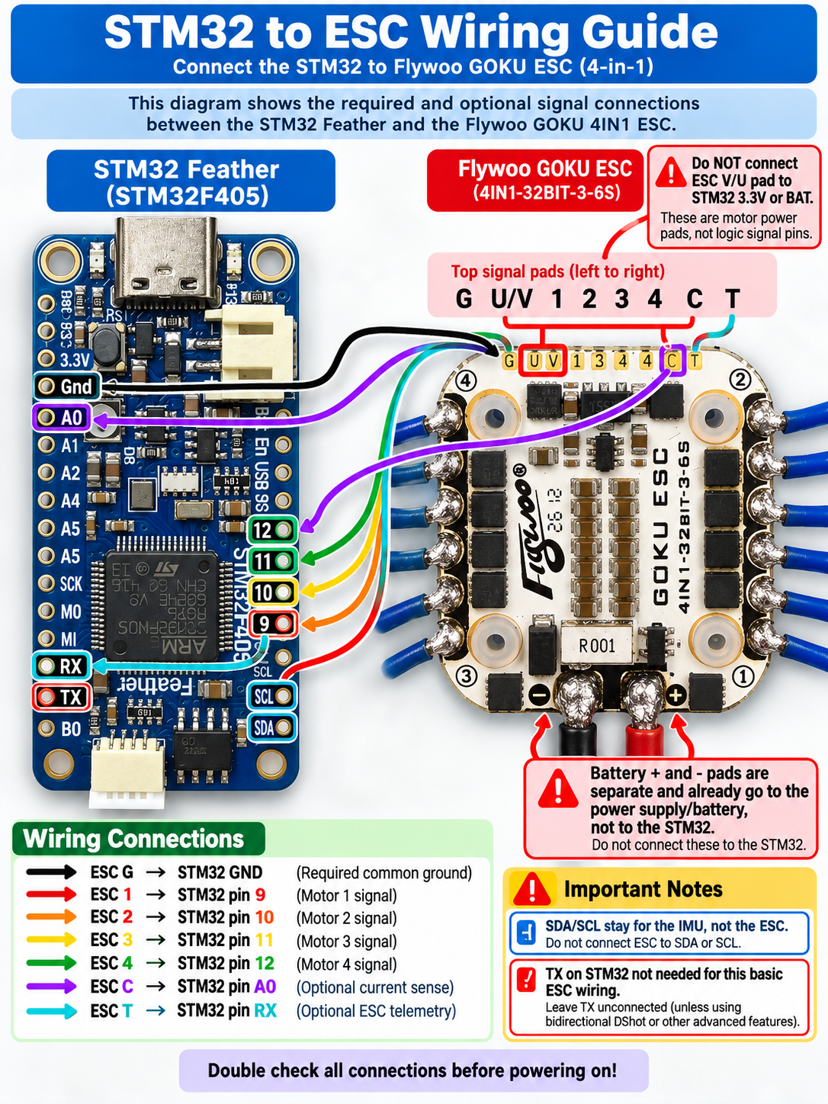
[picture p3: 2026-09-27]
docs/references/control/user-wiring-2.png

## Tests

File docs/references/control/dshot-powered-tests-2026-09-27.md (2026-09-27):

# DShot commissioning — 2026-09-27

Installed image: integrated IMU/individual/all-four v4, 59,740-byte payload;
see [installation record](dshot-v4-install-2026-09-27.md).

## Preconditions

User previously confirmed props removed, all four motors secured, signal rewiring
completed and T disconnected. Before the test the user confirmed battery connected,
startup finished, all motors still and hands clear. No reflash was performed.

The DShot host now requires explicit per-invocation readiness and fresh zero input
on all four channels before enabling. All-four execution requires individual stop
observations. Legacy PWM remains blocked. All 30 host tests pass, including missing
readiness, nonzero initial input, all-four prerequisites and lost-ACK stop behavior.

## Test 1

- Channel: 1 (Feather 9/PB8; planned rear-right).
- Input: 1%, DShot value 67. RPM is unknown.
- Requested duration: 200 ms, bounded by the installed firmware.
- Start/test and explicit zero request acknowledged; no retry.
- Operator observation: only motor 1 spun smoothly, then stopped; all motors still.
- Post-test capture: all requested inputs zero, DS_ACTIVE=0, DS_FAULT=0,
  IMU_OK=1, DS_TOKEN=2; 749 attitude and quaternion packets each in 15 seconds.
  DS_EXPIRE=1 records lease expiration; the specific expiration cause is not reported.
  [Capture](dshot-motor1-after-test-2026-09-27.json).

Read-only post-test telemetry is saved separately. Signal timing, actual
RPM and physical stopping cannot be inferred from firmware telemetry or ACKs.

## Test 2

- Channel: 2 (Feather 10/PB9; planned front-right).
- Input: 1%, DShot value 67; requested duration 200 ms.
- Test and zero request acknowledged; no retry.
- Operator observation: only motor 2 spun smoothly, then stopped; all motors still.
- No simultaneous command sent.

## Test 3

- Channel: 3 (Feather 6/PC6; planned rear-left).
- Input: 1%, DShot value 67; requested duration 200 ms.
- Test and zero request acknowledged; no retry.
- Operator observation: only motor 3 spun smoothly, then stopped; all motors still.

## Test 4

- Channel: 4 (Feather 5/PC7; planned front-left).
- Input: 1%, DShot value 67; requested duration 200 ms.
- Test and zero request acknowledged; no retry.
- Operator observation: only motor 4 spun smoothly, then stopped; all motors still.

## Test 5 — simultaneous all-four

- Sent after all four individual physical motion/stop observations passed.
- Explicit USER_3 all-four command, 1% input (DShot 67), 200 ms.
- Test and zero request acknowledged; no retry.
- Operator confirmed all four spun smoothly and stopped; every motor still.
- Asked operator to unplug ESC battery after completing tests.

These observations validate these five short bench pulses only. RPM, waveform
timing, extended runtime, fault injection, load behavior and flight control remain
unverified. No firmware was reflashed during these tests.

## Final telemetry and requested escalation

The 15-second [post-test capture](dshot-all-after-test-2026-09-27.json)
contains 749 ATTITUDE and 749 quaternion packets, no bad fragments, IMU_OK=1,
DS_FAULT=0, DS_ACTIVE=0 and M1_DS through M4_DS=0. DS_TOKEN=6 is consistent
with five consumed enables. DS_EXPIRE=1 does not identify the expiration cause.

The user subsequently requested all four at 50% for five seconds. No such command
was sent; it exceeds both installed limits (5%, 500 ms). Those limits were retained.

## Test 6 — simultaneous all-four at existing limits

- User requested 5% input for 500 ms and reconfirmed props removed, motors
  secured, battery connected, startup stationary and hands/cables clear.
- Sent one explicit all-four USER_3 request: 5%, DShot value 147, 500 ms.
- Test and zero request acknowledged; no retry. No firmware limits changed.
- Operator confirmed all four spun smoothly and stopped; every motor still.
- Post-test telemetry: all four requested inputs zero, DS_ACTIVE=0, DS_FAULT=0,
  IMU_OK=1, DS_TOKEN=7, no bad fragments; 749 attitude and 749 quaternion
  packets in 15 seconds. RPM remains unmeasured.
- [Post-test capture](dshot-all-5pct-500ms-after-test-2026-09-27.json).

## Test 7 — v5, all four at 5% for one second

After v5 was flashed/readback-verified and its unpowered startup checked, the
operator confirmed props off, all motors secured, battery connected, startup
finished, all motors still and hands/cables clear. Sent one all-four request at
5% input (DShot 147), 1000 ms, with an explicit 5%/1000 ms envelope. Test/stop
were acknowledged; fresh post-stop reports showed DS_ACTIVE=0, DS_FAULT=0 and
all four requested inputs zero. No retry. The user confirmed all four spun smoothly for the pulse and stopped;
every motor still. The post-test capture also showed default limits restored
(5%/500 ms), DS_TOKEN=2 and healthy IMU telemetry.
[Capture](dshot-v5-after-5pct-1000ms-2026-09-27.json).

## Test 8 — v5, all four at 7.5% for one second

After the user confirmed test 7 stopped, sent one all-four request at 7.5% input
(DShot 197), 1000 ms, with an explicit 7.5%/1000 ms envelope. Test/stop
acknowledged; fresh post-stop reports confirmed idle, no output fault and zero
requested inputs. No retry. The user confirmed all four ran smoothly and stopped;
every motor still. [Post-test capture](dshot-v5-after-7p5pct-1000ms-2026-09-27.json)
shows healthy IMU telemetry, no output fault, all inputs zero, DS_TOKEN=3 and the
default 5%/500 ms envelope restored. Asked the user to unplug the ESC battery
after completing this session.

## Test 9 — v5, all four at 50% for 200 ms

The user explicitly requested this pulse and reconfirmed props off, motors firmly
secured, battery connected, startup stationary and hands/cables clear. Sent one
all-four request at 50% input (DShot 1047), 200 ms, with an explicit 50%/200 ms
envelope. Test and stop acknowledged; fresh zero-input and fault-free idle reports
confirmed by the host. No retry. The user confirmed all four ran smoothly and
stopped; every motor still. Asked the user to unplug the ESC battery afterward.
[Post-test capture](dshot-v5-after-50pct-200ms-2026-09-27.json).

## Test 10 — v5, all four at 50% for 2000 ms

The user requested the longer pulse and reconfirmed props off, motors firmly
secured, battery connected, startup stationary and hands/cables clear. Sent one
all-four request at 50% input (DShot 1047), 2000 ms, with an explicit 50%/2000 ms
envelope. Test and stop acknowledged; fresh zero-input and fault-free idle reports
confirmed by the host. No retry. The user confirmed all four ran smoothly and
stopped; every motor still.

Post-test telemetry for test 10: all motor inputs zero, DS_ACTIVE=0, DS_FAULT=0,
IMU_OK=1, IMU_REJ=0, DS_TOKEN=5 and default 5%/500 ms limits restored.
[Capture](dshot-v5-after-50pct-2000ms-2026-09-27.json). The user confirmed physical stopping separately; telemetry does not measure RPM.

## Test 11 — final requested test, v5 all four at 20% for 10 seconds

The user requested this final test and reconfirmed props off, motors firmly
secured, battery connected, startup stationary and hands/cables clear. Sent one
all-four request at 20% input (DShot 447), 10000 ms, with an explicit 20%/10000 ms
envelope. Test and stop acknowledged; fresh zero-input and fault-free idle reports
confirmed by the host. No retry. The user confirmed all four ran smoothly
throughout the full pulse and stopped; every motor still.

Final [15-second capture](dshot-v5-after-20pct-10000ms-2026-09-27.json):
749 attitude and 749 quaternion reports, zero bad fragments, IMU_OK=1, IMU_REJ=0,
DS_FAULT=0, DS_ACTIVE=0, all motor inputs zero, DS_TOKEN=6, and default 5%/500 ms
envelope restored. ESC battery disconnection requested; visualizer restarted.
No more tests were sent after this final requested run. This does not validate
flight, maximum throttle, maximum duration, or behavior with propellers fitted.

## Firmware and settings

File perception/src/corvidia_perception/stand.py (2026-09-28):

"""Person-description stand demo; defaults to real perception and simulated motors.

Only the supervisor renews the motor lease. Inference, HTTP handlers, and file
writes cannot renew it. No service startup or model response can start motors.
"""
from __future__ import annotations

import argparse
from dataclasses import asdict, dataclass
import hashlib
import json
import math
import multiprocessing as mp
import os
from pathlib import Path
import queue
import signal
import threading
import time
import uuid

from .appearance import AppearanceRequirements
from .mission_prompt import parse_mission_prompt
from .stand_motor import MAX_PERCENT


ACTIVE = {"starting", "searching", "confirming", "saving"}
TERMINAL = {"complete", "failed", "timed_out", "cancelled"}
MISSION_PERCENT = 5.0
# One firmware motor run is at most 60 s. Missions without a deadline chain
# fresh one-shot runs; each ends with a verified zero before the next starts.
MOTOR_RUN_MS = 60_000
REARM_TIMEOUT_S = {"stopping": 3.0, "reconnecting": 10.0, "starting": 3.0}
PREPARING_TIMEOUT_S = 15.0
READINESS = {"guarded_stand", "hands_clear", "power_disconnect_accessible", "motors_still", "esc_startup_finished"}


@dataclass(frozen=True)
class MissionSpec:
    mission_id: str
    appearance: str
    requirements: AppearanceRequirements
    percent: float = MISSION_PERCENT
    duration_ms: int | None = None  # None: search until a match or operator abort
    completion_mode: str = "first_match"
    prompt: str = ""

    @classmethod
    def create(cls, appearance, percent=MISSION_PERCENT, duration_ms=None):
        parsed = parse_mission_prompt(appearance)
        if duration_ms is None:
            duration_ms = parsed.duration_ms
        elif parsed.completion_mode == "timed_collection" and duration_ms != parsed.duration_ms:
            raise ValueError("Duration conflicts with the mission brief")
        if isinstance(percent, bool) or not isinstance(percent, (int, float)) or not math.isfinite(percent):
            raise ValueError("Motor input must be a finite number")
        if not 0 < percent <= MAX_PERCENT:
            raise ValueError(f"Stand input must be greater than zero and at most {MAX_PERCENT:g}%")
        if parsed.completion_mode == "timed_collection" and duration_ms is None:
            raise ValueError("Timed collections need a duration")
        if duration_ms is not None and (type(duration_ms) is not int or not 1000 <= duration_ms <= MOTOR_RUN_MS):
            raise ValueError("Duration must be 1,000–60,000 integer milliseconds")
        return cls(uuid.uuid4().hex, parsed.appearance, parsed.requirements, float(percent),
                   duration_ms, parsed.completion_mode, parsed.prompt)

    @property
    def description_sha256(self):
        return hashlib.sha256(self.appearance.encode()).hexdigest()


class AsyncJournal:
    """Bounded audit writer. A stalled disk never stalls the motor supervisor."""
    def __init__(self, root: Path):
        self.root = root
        self.jobs = queue.Queue(maxsize=128)
        self.error = None
        self.busy_since = None
        self.closed = threading.Event()
        self.thread = threading.Thread(target=self._run, daemon=True, name="stand-journal")
        self.thread.start()

    def record(self, row):
        try:
            self.jobs.put_nowait((time.monotonic(), row))
        except queue.Full:
            self.error = "mission audit queue overflow"

    def fault(self):
        if self.busy_since is not None and time.monotonic() - self.busy_since > 2:
            return "mission audit write exceeded two seconds"
        return self.error

    def _run(self):
        while not self.closed.is_set() or not self.jobs.empty():
            try:
                queued, row = self.jobs.get(timeout=.1)
            except queue.Empty:
                continue
            self.busy_since = queued
            try:
                self.root.mkdir(parents=True, exist_ok=True)
                destination = self.root / (row["mission_id"] + ".jsonl")
                with destination.open("a") as stream:
                    stream.write(json.dumps(row, allow_nan=False) + "\n")
                    stream.flush()
                    os.fsync(stream.fileno())
            except Exception as exc:
                self.error = f"mission audit failed: {type(exc).__name__}: {exc}"
            finally:
                self.busy_since = None

    def close(self):
        self.closed.set()
        self.thread.join(2)


class StandSupervisor:
    """Deterministic state machine; tick() is called by one non-GPU thread."""
    def __init__(self, motor_factory, worker_commands, *, mode="observe", clock=time.monotonic,
                 journal=None, evidence_root=None, telemetry_observer=None):
        self.clock, self.mode = clock, mode
        self.motor_factory, self.worker_commands = motor_factory, worker_commands
        self.motor = motor_factory()
        self.motor.start_background()
        self.observer = telemetry_observer
        if self.observer:
            self.observer.start_background()
        self.journal = journal
        self.evidence_root = Path(evidence_root).resolve() if evidence_root else None
        self.commands = queue.Queue(maxsize=16)
        self.lock = threading.Lock()
        self.stop_requested = threading.Event()
        self._pending_mission = None
        self._cancelled_pending = set()
        self.prepare_deadline = None
        self.pending_readiness = {}
        self._snapshot = {}
        self.spec = None
        self.state = "idle"
        self.error = None
        self.guidance = "hold"
        self.perception_ready = False
        self.perception_error = None
        self.source_epoch = None
        self.last_capture = self.last_processed = None
        self.started_mono = self.deadline = self.stopping_mono = None
        self.rearm = self.rearm_started = None
        self.zero_verified_between_runs = False
        self.stage = None
        self.stage_started = None
        self.pending_terminal = None
        self.result_path = None
        self.evidence = None
        self.captures = []
        self.capture_events = set()
        self.capture_tracks = set()
        self.result = None
        self.finished_missions = {}
        self.recovery_required = False
        self.resource_error = None
        self.memory_available_mib = None
        self.resource_checked_mono = None
        self._publish()

    def submit(self, message):
        """Reserve one complete mission; clients cannot choose motor settings."""
        action = message.get("action")
        if action == "stop":
            if set(message) - {"action", "mission_id"}:
                raise ValueError("Unexpected command field")
            with self.lock:
                requested = message.get("mission_id")
                if self._pending_mission and requested == self._pending_mission:
                    self._cancelled_pending.add(requested)
                elif requested is not None and requested == self._snapshot.get("mission_id"):
                    self.stop_requested.set()
                else:
                    raise ValueError("Mission does not match current session")
            return {"accepted": True}
        if action != "mission":
            raise ValueError("Unknown action; submit a mission or stop it")
        if set(message) - {"action", "appearance", "readiness"}:
            raise ValueError("Mission input cannot set motor power or raw timing fields; use the mission brief")
        spec = MissionSpec.create(message.get("appearance"))
        readiness = message.get("readiness", {})
        if not isinstance(readiness, dict) or (readiness and
                (set(readiness) != READINESS or any(v is not True for v in readiness.values()))):
            raise ValueError("Confirm all five readiness observations")
        if self.mode == "hardware" and set(readiness) != READINESS:
            raise ValueError("Confirm guarded stand, hands clear, and accessible power disconnect")
        if self.mode == "telemetry":
            raise ValueError("Telemetry mode cannot run missions")
        with self.lock:
            if self.recovery_required:
                raise ValueError("Stop was unverified: verify physical stopping and restart the service")
            if self._pending_mission or self._snapshot.get("state") not in ({"idle"} | TERMINAL):
                raise ValueError("A mission is already in progress")
            self._pending_mission = spec.mission_id
            try:
                self.commands.put_nowait({"action": "mission", "spec": spec,
                                         "readiness": dict(readiness), "submitted_mono": self.clock()})
            except queue.Full:
                self._pending_mission = None
                raise ValueError("Command queue full") from None
        return {"accepted": True, "mission_id": spec.mission_id}

    def snapshot(self):
        with self.lock:
            return dict(self._snapshot)

    def _audit(self, event, **extra):
        if self.journal is not None and self.spec is not None:
            telemetry = self.observer.snapshot() if self.observer else self.motor.snapshot()
            self.journal.record({"mission_id": self.spec.mission_id, "mono": self.clock(),
                                 "wall": time.time(), "event": event, "state": self.state,
                                 "mode": self.mode, "raw_sensor_telemetry": telemetry.get("telemetry", {}),
                                 "telemetry_received_mono": telemetry.get("telemetry_received_mono", {}),
                                 "telemetry_simulated": self.mode == "observe" and self.observer is None,
                                 "attitude_frame": "sensor", "capture_time_alignment": "unavailable", **extra})

    def _send(self, message):
        try:
            self.worker_commands.put_nowait(message)
            return True
        except queue.Full:
            if self.state in ACTIVE:
                self._stop("perception command queue overflow", "failed")
            else:
                self.error = "perception command queue overflow"
            return False

    def _fresh(self, now):
        return (self.perception_ready and self.last_capture is not None and self.last_processed is not None
                and 0 <= now - self.last_capture <= .5 and 0 <= now - self.last_processed <= .5)

    def _prepare(self, message):
        if self.recovery_required:
            raise ValueError("Stop was unverified: verify physical stopping and restart the service")
        if self.state in ACTIVE or self.state in {"preparing", "stopping"}:
            raise ValueError("Stop the current mission before preparing another")
        if self.mode == "telemetry":
            raise ValueError("Telemetry mode only reads USB; start observation mode to rehearse")
        if self.state in TERMINAL:
            # One motor object owns one operator run. Never reuse a consumed token/session.
            self.motor.close()
            self.motor = self.motor_factory()
            self.motor.start_background()
        self.spec = message.get("spec") or MissionSpec.create(
            message.get("appearance"), message.get("percent", MISSION_PERCENT),
            message.get("duration_ms"))
        self.state, self.error, self.guidance = "prepared", None, "hold"
        self.started_mono = self.deadline = self.stopping_mono = None
        self.rearm = self.rearm_started = None
        self.zero_verified_between_runs = False
        self.stage = self.stage_started = self.pending_terminal = None
        self.evidence = self.result_path = self.result = None
        self.captures = []
        self.capture_events = set()
        self.capture_tracks = set()
        self.stop_requested.clear()
        self._audit("prepared", settings=asdict(self.spec), description_sha256=self.spec.description_sha256)

    def _start(self, message):
        if not self.spec or message.get("mission_id") != self.spec.mission_id:
            raise ValueError("Prepare and review this mission first")
        if self.state not in {"prepared", "preparing"}:
            raise ValueError("Start is accepted once per prepared mission")
        if self.mode == "hardware" and not all(message.get("readiness", {}).get(k) is True for k in READINESS):
            raise ValueError("Confirm guarded stand, hands clear, and accessible power disconnect")
        now = self.clock()
        if self.state == "preparing" and now >= self.prepare_deadline:
            raise ValueError("mission preflight deadline expired")
        if not self._fresh(now):
            raise ValueError("Waiting for fresh camera and detector progress")
        if not self.motor.snapshot().get("ready"):
            raise ValueError("Motor interface is not ready")
        if self.observer and not self.observer.snapshot().get("ready"):
            raise ValueError("Waiting for healthy read-only STM32 telemetry")
        if self.resource_error:
            raise ValueError(self.resource_error)
        if self.memory_available_mib is None:
            raise ValueError("Waiting for Jetson memory headroom measurement")
        if self.journal and self.journal.fault():
            raise ValueError(self.journal.fault())
        # Serialize the final start decision with HTTP Abort admission. All motor
        # methods here only update/enqueue bounded in-memory state, never do I/O.
        with self.lock:
            cancelled = (self.spec.mission_id in self._cancelled_pending
                         or self.stop_requested.is_set())
            if not cancelled:
                now = self.clock()
                if self.state == "preparing" and now >= self.prepare_deadline:
                    raise ValueError("mission preflight deadline expired")
                if not self._fresh(now):
                    raise ValueError("Waiting for fresh camera and detector progress")
                duration = self.spec.duration_ms
                self.started_mono = now
                self.deadline = math.inf if duration is None else now + duration / 1000
                self.state, self.error = "starting", None
                self.motor.refresh_lease()
                self.motor.start_all(self.spec.percent, duration or MOTOR_RUN_MS)
        if cancelled:
            self._stop("operator stop", "cancelled")
            return
        self._audit("start_requested", settings=asdict(self.spec))

    def _stop(self, reason, terminal):
        if self.state == "stopping":
            if self.pending_terminal == "complete" and terminal != "complete":
                self.pending_terminal, self.error = terminal, reason
            return
        if self.state in TERMINAL:
            return
        if self.state not in ACTIVE:
            if self.state in {"prepared", "preparing"}:
                self.state, self.error = terminal, reason
                self._audit("mission_ended_before_start", reason=reason, terminal=terminal)
            return
        # Revoke motor authority before any queue, file, model or HTTP operation.
        self.motor.stop(reason)
        # Between chained runs the previous run's zero is already verified and the
        # fresh session has commanded nothing, so its stop need not be re-verified.
        self.zero_verified_between_runs = self.rearm == "reconnecting"
        self.perception_ready = False  # Require a new ready after model cleanup.
        self.state, self.pending_terminal = "stopping", terminal
        self.error = None if terminal == "complete" else reason
        self.guidance, self.stopping_mono = "hold", self.clock()
        if terminal == "complete" and self.evidence is not None:
            for source, metric in (("capture_mono", "capture_to_stop_request_ms"),
                                   ("commit_mono", "commit_to_stop_request_ms")):
                value = self.evidence.get(source)
                if isinstance(value, (int, float)) and math.isfinite(value):
                    self.evidence[metric] = (self.stopping_mono - value) * 1000
        self._audit("stop_requested", reason=reason, terminal=terminal, motor=self.motor.snapshot())
        try:
            self.worker_commands.put_nowait({"type": "end", "mission_id": self.spec.mission_id})
        except queue.Full:
            pass  # Motor authority has already been revoked.

    def _active_failure(self, now, motor):
        """The same checks apply before accepting success and renewing authority."""
        fault = self.resource_error or (self.journal.fault() if self.journal else None)
        if self.observer and not self.observer.snapshot().get("ready"):
            fault = "live STM32 telemetry unhealthy"
        if fault:
            return fault, "failed"
        if not self._fresh(now):
            return "camera or detector progress stale", "failed"
        if motor.get("error") or motor.get("fault") or motor.get("start_status") == "failed":
            return str(motor.get("error") or motor.get("fault") or "motor start failed"), "failed"
        if self.stage and now - self.stage_started > (2 if self.stage == "saving" else 4):
            return self.stage + " deadline exceeded", "failed"
        if self.state == "starting" and now - self.started_mono > 3:
            return "motor start acknowledgement timed out", "failed"
        if self.rearm and now - self.rearm_started > REARM_TIMEOUT_S[self.rearm]:
            return f"motor re-arm {self.rearm} timed out", "failed"
        if now >= self.deadline:
            return self._deadline_outcome()
        return None

    def _deadline_outcome(self):
        if self.state == "starting":
            return "mission expired before motor start acknowledgement", "failed"
        if self.spec.completion_mode == "timed_collection":
            return "collection time elapsed", "complete"
        return "mission time limit", "timed_out"
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

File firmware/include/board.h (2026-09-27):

// ============================================================================
//  board.h  --  Hardware pin map & board constants
//  Adafruit Feather STM32F405 Express (#4382)
//  Pins verified against Adafruit's published pinout.
// ============================================================================
#pragma once

#include <Arduino.h>

// ---- Status LED -------------------------------------------------------------
// Red LED next to the USB jack. On this core LED_BUILTIN is defined, but we
// pin it explicitly to PC1 to be unambiguous.
#ifndef LED_BUILTIN
#define LED_BUILTIN PC1
#endif
static const uint8_t PIN_LED = LED_BUILTIN;

// ---- Onboard NeoPixel (RGB status LED) --------------------------------------
// The mini NeoPixel next to the reset button, on PC0. Used as a dim status
// indicator (green = healthy, red = fault, amber = booting). Fully dimmable via
// its brightness setting, unlike the red LED (which has no PWM).
static const uint8_t PIN_NEOPIXEL = PC0;
static const uint8_t NEOPIXEL_BRIGHTNESS = 4;   // 0..255; keep it dim (~1.5%)

// ---- I2C (BNO085 via STEMMA QT) ---------------------------------------------
// SDA = PB7, SCL = PB6. Board has 10K pullups to 3.3V on both lines.
// The STM32duino default `Wire` maps to these on this board, so we just use
// Wire directly; these are documented here for reference.
static const uint8_t PIN_I2C_SDA = PB7;
static const uint8_t PIN_I2C_SCL = PB6;

// ---- Serial / console -------------------------------------------------------
// `Serial` = native USB-C CDC (console + Jetson link during bring-up).
// Serial3 (PB10 TX / PB11 RX) is reserved for the flight-time Jetson UART link.
static const uint32_t CONSOLE_BAUD = 115200;

// ---- Loop timing ------------------------------------------------------------
// Phase 0 just prints; we still establish the fixed-rate scheduler pattern so
// later phases drop straight in. 50 Hz is plenty for a print/telemetry task.
static const uint32_t PRINT_HZ = 50;

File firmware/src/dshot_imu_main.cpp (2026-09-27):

// IMU telemetry + operator-only bounded individual/all-four DShot tests. No mixer.
#include <Arduino.h>
#include <Wire.h>
#include "dshot_output.h"
#include "dshot_protocol.h"
#include "imu.h"
#include "rate_timer.h"

namespace {
Imu imu;
DshotTest test;
bool imuOk = false;
uint32_t bootAt = 0, resets = 0;
RateTimer attitudeTimer(50), statusTimer(40);
unsigned field = 0;
mavlink_message_t rx{};
mavlink_status_t parser{};

bool send(mavlink_message_t& m) {
    uint8_t bytes[MAVLINK_MAX_PACKET_LEN];
    const auto n = mavlink_msg_to_send_buffer(bytes, &m);
    if (Serial.availableForWrite() < n) return false;
    return Serial.write(bytes, n) == n;
}
bool named(const char* label, int32_t value) {
    char name[10]{};
    snprintf(name, sizeof(name), "%s", label);
    mavlink_message_t m;
    mavlink_msg_named_value_int_pack(1, 1, &m, millis(), name, value);
    return send(m);
}
void ack(uint16_t command, uint8_t result) {
    mavlink_message_t m;
    mavlink_msg_command_ack_pack(1, 1, &m, command, result, 0, 0,
        BenchProtocol::OPERATOR_SYSTEM, BenchProtocol::OPERATOR_COMPONENT);
    send(m);
}
bool healthy() { return imuOk && imu.healthy() && !DshotOutput::faulted(); }
void stop() { test.stop(); DshotOutput::stop(); }
void supervise() {
    if (imu.resetCount() != resets) { resets = imu.resetCount(); stop(); }
    test.update(millis(), healthy());
    if (test.active() && DshotOutput::expired()) stop();
    if (!test.active()) DshotOutput::stop();
}
void handle() {
    if (!BenchProtocol::fromOperator(rx)) return;
    supervise();
    const auto now = millis();
    if (rx.msgid == MAVLINK_MSG_ID_HEARTBEAT) {
        if (mavlink_msg_heartbeat_get_type(&rx) == MAV_TYPE_GCS) test.heartbeat(now);
        return;
    }
    if (rx.msgid != MAVLINK_MSG_ID_COMMAND_LONG) return;
    mavlink_command_long_t c;
    mavlink_msg_command_long_decode(&rx, &c);
    if (!BenchProtocol::addressed(c)) return;
    if ((c.command == DshotProtocol::ENABLE || c.command == MAV_CMD_COMPONENT_ARM_DISARM)
        && DshotProtocol::stopShape(c)) {
        stop(); ack(c.command, MAV_RESULT_ACCEPTED); return;
    }
    if (c.command == DshotProtocol::ENABLE) {
        if (!DshotProtocol::enableShape(c)) { ack(c.command, MAV_RESULT_DENIED); return; }
        const bool ready = healthy() && DshotOutput::motorTestsAllowed() &&
            uint32_t(now-bootAt) >= 3000;
        const bool ok = test.enable(now, uint32_t(c.param2), ready, DshotProtocol::limits(c));
        ack(c.command, ok ? MAV_RESULT_ACCEPTED : MAV_RESULT_TEMPORARILY_REJECTED);
    } else if (c.command == DshotProtocol::TEST || c.command == DshotProtocol::TEST_ALL) {
        const bool all = c.command == DshotProtocol::TEST_ALL;
        if (!(all ? DshotProtocol::allShape(c) : DshotProtocol::testShape(c))) {
            ack(c.command, MAV_RESULT_DENIED); return;
        }
        const auto motor = all ? DshotTest::ALL_MOTORS : uint8_t(c.param1);
        const auto throttle = DshotProtocol::throttle(c.param2);
        const auto duration = uint32_t(c.param3);
        bool ok = test.start(now, uint32_t(c.param4), motor, throttle, duration);
        if (ok && !DshotOutput::start(motor, throttle, duration, imu.lastUpdateMs(),
                                     imu.gyroUpdateMs(), test.heartbeatAt(), test.limits())) { stop(); ok = false; }
        ack(c.command, ok ? MAV_RESULT_ACCEPTED : MAV_RESULT_TEMPORARILY_REJECTED);
    } else {
        // Reject arming, PWM DO_MOTOR_TEST, setpoints and ESC-setting commands.
        ack(c.command, MAV_RESULT_UNSUPPORTED);
    }
}
bool status() {
    mavlink_message_t m;
    bool sent = false;
    switch (field) {
        case 0:
            mavlink_msg_heartbeat_pack(1, 1, &m, MAV_TYPE_QUADROTOR,
                MAV_AUTOPILOT_INVALID, 0, DshotProtocol::MODE,
                !healthy() ? MAV_STATE_CRITICAL :
                test.active() ? MAV_STATE_ACTIVE : MAV_STATE_STANDBY);
            sent = send(m); break;
        case 1: sent = named("IMU_OK", imuOk && imu.healthy()); break;
        case 2: sent = named("ATT_AGE", imuOk ? int32_t(millis()-imu.lastUpdateMs()) : -1); break;
        case 3: sent = named("DS_FAULT", DshotOutput::faulted()); break;
        case 4: sent = named("DS_OUTPUT", DshotOutput::ready()); break;
        case 5: sent = named("DS_ALLOW", DshotOutput::motorTestsAllowed()); break;
        case 6: sent = named("DS_TOKEN", test.nextToken()); break;
        case 7: sent = named("DS_ACTIVE", test.active()); break;
        case 8: sent = named("DS_EXPIRE", DshotOutput::expired()); break;
        case 9: sent = named("DS_FRAMES", DshotOutput::frames()); break;
        case 10: sent = named("M1_DS", DshotOutput::commanded(1)); break;
        case 11: sent = named("M2_DS", DshotOutput::commanded(2)); break;
        case 12: sent = named("M3_DS", DshotOutput::commanded(3)); break;
        case 13: sent = named("M4_DS", DshotOutput::commanded(4)); break;
        case 14: sent = named("GYR_AGE", imuOk ? int32_t(millis()-imu.gyroUpdateMs()) : -1); break;
        case 15: sent = named("IMU_INIT", imu.initStatus()); break;
        case 16: sent = named("IMU_ADDR", imu.address()); break;
        case 17: sent = named("I2C_MASK", imu.addressMask()); break;
        case 18: sent = named("IMU_ATT", imu.attitudeReports()); break;
        case 19: sent = named("IMU_GYR", imu.gyroReports()); break;
        case 20: sent = named("IMU_REJ", imu.rejectedReports()); break;
        case 21: sent = named("DS_ALL", DshotOutput::motorTestsAllowed()); break;
        case 22: sent = named("FW_REV", DshotProtocol::REVISION); break;
        case 23: sent = named("DS_MAXP", 100); break;
        case 24: sent = named("DS_MAXMS", DshotLimits::MAX_DURATION_MS); break;
        case 25: sent = named("DS_CAP_BP", int32_t(test.limits().percent * 100)); break;
        case 26: sent = named("DS_CAP_MS", test.limits().durationMs); break;
        case 27: sent = named("FLT_READY", 0); break;
        case 28: sent = named("AXES_OK", 0); break; // fine alignment not applied
#if CORVIDIA_DSHOT_RAMP_MS
        case 29: sent = named("DS_RAMPMS", DshotProtocol::RAMP_MS); break;
#endif
    }
    if (sent) field = (field + 1) % (DshotProtocol::RAMP_MS ? 30 : 29);
    return sent;
}
}
void setup() {
    Serial.begin(115200);
    // Keep the motor pads low while the IMU starts; no DShot timer interrupt
    // runs during its initialization handshake.
    for (const uint32_t pin : {PB8, PB9, PC6, PC7}) {
        digitalWrite(pin, LOW); pinMode(pin, OUTPUT);
    }
    Wire.begin(); Wire.setClock(400000);
    imuOk = imu.begin();
    DshotOutput::begin();
    bootAt = millis();
}
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

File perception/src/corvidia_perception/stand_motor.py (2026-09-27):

"""One-shot, operator-bounded MAVLink motor session for a restrained stand demo.

This is not a flight controller. Only this worker owns the serial port. The LLM
must never receive this object: the deterministic supervisor owns its lease.
Importing this module needs neither pyserial nor pymavlink; simulation needs neither.
"""
from __future__ import annotations

import copy
import math
import threading
import time
from collections import deque
from typing import Callable

MODE_ID = 0x44534935
ENABLE_COMMAND, ALL_COMMAND = 31010, 31012
MAX_PERCENT, MAX_DURATION_MS = 7.5, 60000
LEASE_S, HEARTBEAT_S = .250, .100
STATUS_MAX_AGE_S = 1.5
ACK_TIMEOUT_S, STOP_TIMEOUT_S = 1.0, 2.0
_READY = {"DS_ALLOW": 1, "DS_OUTPUT": 1, "DS_ALL": 1, "DS_FAULT": 0,
          "IMU_OK": 1, "DS_ACTIVE": 0, "M1_DS": 0, "M2_DS": 0,
          "M3_DS": 0, "M4_DS": 0, "FW_REV": 5, "DS_MAXP": 100,
          "DS_MAXMS": 60000, "FLT_READY": 0}
_ZERO = ("DS_ACTIVE", "DS_FAULT", "M1_DS", "M2_DS", "M3_DS", "M4_DS")


def _validate(percent, duration_ms):
    if type(percent) not in (int, float) or not math.isfinite(percent) or not 0 < percent <= MAX_PERCENT:
        raise ValueError(f"stand input must be finite and in (0, {MAX_PERCENT:g}] percent")
    if type(duration_ms) is not int or not 20 <= duration_ms <= MAX_DURATION_MS:
        raise ValueError("stand duration must be an integer in [20, 60000] ms")


class _SerialTransport:
    def __init__(self, port: str):
        import serial
        from pymavlink.dialects.v20 import common
        self._serial = serial.Serial(port, 115200, timeout=.01, write_timeout=.05, exclusive=True)
        self._mav = common.MAVLink(self, srcSystem=255, srcComponent=190)
        self._mav.robust_parsing = True

    def write(self, data):
        if self._serial.write(data) != len(data):
            raise OSError("partial MAVLink write")

    def receive(self):
        data = self._serial.read(min(4096, max(1, self._serial.in_waiting)))
        return self._mav.parse_buffer(data) or []

    def heartbeat(self):
        self._mav.heartbeat_send(6, 8, 0, 0, 0)  # GCS, autopilot invalid

    def command(self, number, params):
        self._mav.command_long_send(1, 1, number, 0, *params)

    def close(self):
        self._serial.close()


class MotorSession:
    """Real serial session; execute=False is strictly read-only.

    start_all queues one run after ready=True. refresh_lease must be called by
    healthy mission supervision at least every 250 ms until stopping. No command
    enables a new run after this session has stopped or failed. snapshot never
    blocks on serial I/O. A fresh session is required for a new operator mission.
    """
    def __init__(self, port: str, *, execute: bool = False,
                 _clock: Callable[[], float] = time.monotonic,
                 _transport_factory=None):
        self.port, self.execute = port, execute
        self._clock = _clock
        self._factory = _transport_factory or _SerialTransport
        self._lock = threading.RLock()
        self._wake = threading.Event()
        self._cancel = threading.Event()
        self._quit = threading.Event()
        self._thread = None
        self._transport = None
        self._identified = False
        self._used = False
        self._lease_at = -math.inf
        self._heartbeat_at = -math.inf
        self._identified_at = None
        self._request = None
        self._token = None
        self._pending = deque()
        self._stop_sent = False
        self._stop_ack_at = None
        self._run_deadline = None
        self._last_imu_stamp = None
        self._last_imu_progress = None
        self._max_boot_ms = None
        self._state = dict(ready=False, connected=False, active=False,
                           zero_confirmed=False, fault=False, error=None,
                           mode="execute" if execute else "read_only", phase="new",
                           start_status="not_requested", stop_status="not_requested",
                           telemetry={}, telemetry_received_mono={}, timestamps={},
                           requested_percent=None, duration_ms=None, stop_reason=None,
                           firmware_mode=None, physical_stop_measured=False)

    def start_background(self):
        with self._lock:
            if self._thread is not None or self._state["phase"] != "new":
                raise RuntimeError("motor session has already been started")
            self._state["phase"] = "connecting"
            self._thread = threading.Thread(target=self._run, name="stand-mavlink", daemon=True)
            self._thread.start()
        return self

    def snapshot(self) -> dict:
        with self._lock:
            return copy.deepcopy(self._state)

    def refresh_lease(self):
        with self._lock:
            if not self._cancel.is_set():
                self._lease_at = self._clock()
        self._wake.set()
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

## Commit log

2026-09-26 Add final compact frame and P2S print package under hardware
    [Corvidia_Compact.FCStd, Corvidia_Compact.step, Corvidia_Compact.stl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]
2026-09-27 Add person detection event pipeline (spec steps 1-2)
    Step 1, event core: typed records, candidate gate and lifecycle, bounded
    confirmation queue, confirmer backend protocol with strict answer parsing
    and stub backends, evidence store with atomic writes, storage limits and
    interrupted-event recovery, and deterministic tests for the spec's
    behavioral checks.
    Step 2, video replay and live camera: YOLO11n (.pt or TensorRT engine)
    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
2026-09-27 Add local Cosmos confirmer and PyTorch-free TensorRT detector (spec step 3)
    Cosmos Reason 2 2B runs in the Jetson AI Lab llama.cpp container (pinned
    image digest, sha256-checked Q4_K_M weights, 127.0.0.1:8010, -c 2048 -np 1
    -cram 0 for RAM headroom). The adapter constrains answers with a JSON
    schema, never retries, records token usage and server timings, and only
    acknowledges a cancel once /slots reports the server idle. Crops sent to
    the model are capped at 448 px; crop.jpg is the exact submitted image.
    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
2026-09-27 Add GStreamer camera capture, sensor-mode selection and soak tooling (spec step 4)
    Camera frames now come from a GStreamer pipeline read through PyGObject.
    Each frame carries the Argus buffer timestamp on CLOCK_MONOTONIC as its
    capture time (labelled argus_buffer_pts: Argus delivery, not exposure),
    falling back to host arrival time. Camera loss still reconnects with a new
    source epoch.
    The sensor mode is selectable (--sensor-mode 0 = 4K30, 1 = 1080p60); the
    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
2026-09-27 Add per-event depth, best-shot images and step 5 evaluation tooling
    Depth: Depth Anything V2 Metric Small (indoor/outdoor) exported to ONNX and
    run as an FP16 TensorRT engine once per event on the confirmation worker,
    in parallel with Cosmos. Events record distance_m (median over the torso
    region) marked uncalibrated until a tape-measure scale is set;
    corvidia-depth-check gives a live readout for that check.
    Best shot: the clearest view of each track (confidence x size x sharpness,
    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
2026-09-27 Add the free-space depth stream and the laptop evaluation harness
    Pipeline order for a moving platform: the depth engine runs on its own thread at a
    fixed rate and publishes an obstacle free-space profile; the detector thread tracks
    people and the gate stores evidence with per-event distance; no confirmer sits in
    the loop (--stub-delay 0; Cosmos stays optional).
    - freespace.py: sector "nearest" distances and free scores from a metric depth map,
    ported from the autodrone framework with the same wire fields (t, columns,
    center_free, all_close, hfov_deg, nearest_m).
    - depth_stream.py: FreeSpaceStream, a one-frame fan-out from the run loop, paced at
    [freespace] hz, stamped at publish time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
    [config.py, depth.py, depth_stream.py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]
2026-09-27 Add the tracks publisher and the Corvidia -> autodrone bridge
    Closes the gap between this pipeline and the autodrone mission loop. Corvidia keeps the
    camera and the GPU models; two UDP streams and the evidence store now carry everything
    the framework's broker, fc, control and mission nodes consume.
    Package:
    - tracks_stream.py: --tracks-udp host:port publishes per-frame person tracks after
    ByteTrack ({"t", "frame_id", "source_epoch", "width", "height", "tracks": [{"id",
    "x1", "y1", "x2", "y2", "conf", "age", "depth_m"}]}, the PersonTracks contract).
    Boxes normalized, age = processed frames seen in the epoch, depth_m = torso median
    from the free-space stream's newest map (FreeSpaceStr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
    [config.py, depth_stream.py, run.py]
2026-09-27 Record timed capture validation with live IMU telemetry
2026-09-27 Accept shorter timed briefs and use a fixed 25 percent mission input
    [mission_prompt.py, stand.py, stand_cli.py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]
2026-09-27 Record powered 25 percent GUI mission validation
2026-09-27 Distinguish reported motor commands from observed movement
2026-09-27 Add STM32 firmware and hardware records for the low-power stand demo
    [dshot-motor1-after-test-2026-09-27.json, motor-directions-2026-09-27.json]
2026-09-28 Open-ended stand missions, 30 fps console and plain-language redesign
    Missions without a stated time now search until a match or Stop. Each
    motor run stays a one-shot session of at most 60 s (the firmware cap);
    after a clean, verified expiry the supervisor opens a fresh session and
    starts the next run. Faults and operator stops are never chained, each
    re-arm stage is time-bounded, and stopping between runs relies on the
    previous run's verified zero.
    Performance on the Orin:
    - OPENBLAS_NUM_THREADS=1 for the perception worker. numpy's OpenBLAS
    pool spun five cores after every threaded product (worker CPU 483% ->
    82%, frame age median 115 ms -> 39 ms).
    - Argus frames arrive as BGRx; the on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
    [mission_prompt.py, sources.py, stand.py]

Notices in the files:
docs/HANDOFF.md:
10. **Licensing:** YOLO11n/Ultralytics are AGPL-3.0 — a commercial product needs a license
